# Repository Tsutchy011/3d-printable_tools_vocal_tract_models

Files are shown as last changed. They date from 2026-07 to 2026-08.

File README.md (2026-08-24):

# 3D printable tools for vocal tract models

声道模型を用いた音響教育（音源フィルタ理論のデモンストレーション・実習）のために作成した、
3Dプリンタで印刷可能なモデル一式です。

上智大学 荒井研究室「音響音声学デモンストレーション (Acoustic-Phonetics Demonstrations; APD)」で公開されている
**日本語5母音の声道模型 (VTM-T20)** に対応するリード式音源・ケースの他、
スライド式3音響管・それに対応するリード式音源、リードを切り出すための治具などのアタッチメントを収録しています。

- 出典: 辻慎也, 荒井隆行, 「3Dプリンタを活用した音響教育のための教材作成
  ——言語聴覚士養成コースでの取り組み事例——」, 日本音響学会講演論文集, Sep. 2026.
  
- 関連:
  - [Acoustic-Phonetics Demonstrations (APD)](https://splab.net/apd/)
  - [日本語5母音の声道模型（VTM-T20）](https://splab.net/apd/v100/)
  - [本モデルが対応している教科書（最新言語聴覚講座 音響学）](https://store.isho.jp/search/detail/productId/2607204890)

> **License:** [CC BY 4.0](https://creativecommons.org/licenses/by/4.0/)  
> 辻慎也・荒井隆行（上智大学）, *3D printable tools for vocal tract models*, 2026.  
> https://github.com/Tsutchy011/3d-printable_tools_vocal_tract_models
>
> なお本アタッチメントの一部は、上智大学荒井研究室が公開する声道模型 VTM-T20 に
> 対応するよう設計したものです。VTM-T20 本体のデータは上記のリンクよりダウンロードできます。<br>
> その利用については APD の利用条件に従ってください。
> https://splab.net/apd/termsofuse

---

## 1. 動作環境

| 項目 | 本稿で使用したもの |
|---|---|
| 3D CAD | OpenSCAD 2021.01 |
| スライサー | eufyMake Studio 3D (Anker) |
| 3Dプリンタ | AnkerMake M5 (Anker), 造形範囲 235 × 235 × 250 mm |
| 素材 | PLA |

`.scad` を編集すれば寸法を変更できます。<br>
編集せずに使う場合は `.stl` をそのままスライサーに読み込んでください。

---

## 2. ファイル一覧

```
3d-printable_tools_vocal_tract_models/
├── 01_スライド式3音響管/
├── 02_リード式音源/
├── 03_リード裁断用の治具_リードケース/
├── 04_ケース類/
└── 05_空気ポンプ用の追加パーツ/
```

各パーツにつき `.stl`（そのまま印刷可）と `.scad`（寸法を変更したい場合の設計ファイル）を
同じフォルダに収めています。

### 2-1. スライド式3音響管

| ファイル | 内容 | ソース |
|---|---|---|
| `01_スライド式3音響管/acoustic_tube_ID20mm_170mm.stl` | スライド式3音響管の音響管本体です。 | `acoustic_tube_ID20mm_170mm.scad` |
| `01_スライド式3音響管/sliding_three_tube_part.stl` | 狭めのスライダーと、それを操作するトロンボーン式ロッドのセットです。 | `sliding_three_tube_part.scad` |

> 音響管本体は透明な素材でプリントしていただくか、透明アクリル管（市販のもの; 内径20 mm）を音響管の代わりに使うと、
> スライダーの動きが見えるため教育効果が高くなります。

### 2-2. リード式音源

| ファイル | 内容 | ソース |
|---|---|---|
| `02_リード式音源/reed_type_sound_source_ID20mm_S3T.stl` | **スライド式3音響管用** の音源部分本体です。 | `リード式音源部分_2パターンで出力.scad` (`"20MM"`) |
| `02_リード式音源/reed_type_sound_source_ID10mm_VTM.stl` | **VTM-T20用** の音源部分本体です。 | 同上 (`"10MM"`) |
| `02_リード式音源/reed_fixing_part_200μm.stl` | **リードの厚み0.2 mm 用** のリード固定パーツです。 | `リード部分.scad` (`reed_thickness = 0.2`) |
| `02_リード式音源/reed_fixing_part_300μm.stl` | **リードの厚み0.3 mm 用** のリード固定パーツです。 | 同上 (`reed_thickness = 0.3`) |

### 2-3. リード裁断用の治具・リードケース

| ファイル | 内容 | ソース |
|---|---|---|
| `03_リード裁断用の治具_リードケース/reed_cutter.stl` | リード裁断治具。4パーツを一括して印刷できるよう配置してあります。 | `reed_cutter.scad` (`"ALL"`) |
| `03_リード裁断用の治具_リードケース/reed_case.stl` | リードケース（本体カートリッジ＋保護スリーブ） | `reed_case.scad` |

### 2-4. ケース類

| ファイル | 内容 | ソース |
|---|---|---|
| `04_ケース類/VTM_T20_case.stl` | VTM-T20 収納・展示ケースの本体（5本用） | `VTM_T20_case.scad` |
| `04_ケース類/VTM_T20_case_lid.stl` | 同ケースの蓋。5本を固定するペグ付き | `VTM_T20_case_lid.scad` |

### 2-5. 空気ポンプ用の追加パーツ

| ファイル | 内容 | ソース |
|---|---|---|
| `05_空気ポンプ用の追加パーツ/reed_flow_reducer.stl` | リード式音源用の気流リデューサ | `reed_flow_reducer.scad` |

> 空気ポンプで2-2のリード式音源を駆動した場合、過剰に励起していい音になりにくいことがあります。<br>
> その場合には、上記の気流リデューサを空気ポンプとリード式音源の間に接続してお使いください。

---

## 3. 印刷のコツ（パーツ別）

各STLはサポート材不要の姿勢で保存しています。

### 音響管 `acoustic_tube_ID20mm_170mm.stl`
- **立てて（縦置きで）**印刷する配置になっています。
- 高さ 170 mmで接地面が細いため**ブリム（brim）を推奨**します。
- 内径は 20.0 mm ではなく **20.3 mm** で設計しています。樹脂の収縮を見込んだ値で、
  出力後の実寸がおよそ 20 mm になります。**内径が小さすぎる場合はこの補正値
  (`hole_compensation`) を大きく**してください。
- 外周の3点リブは反り・たわみ防止用です。

### スライダーとロッド `sliding_three_tube_part.stl`
- スライダーは**立てて**、ロッドは**寝かせて**印刷する配置になっています。
  （この向きならサポート材は不要で、ロッドも折れにくくなります）
- ロッドの穴に差し込むと固定されるように作られていますが、固定されない場合には接着剤などお使いください。
- 管内での動きが悪い場合は `body_outer_dia`（既定 19.6 mm）を 0.1 mm 単位で小さくします。

### リード式音源カプセル
- **プラグを上にして逆さに置いた状態**にしてあります。
- プラグが固くて入らない／緩い場合は、`.scad` の `plug_outer_diameter`
  （VTM-T20用 9.7 mm）や `plug_tip_diameter` / `plug_root_diameter`
  （3音響管用 19.5 / 19.9 mm）を 0.1 mm 単位で調整してください。

### リード固定パーツ
- スリット高は `reed_thickness + slot_vertical_clearance`（既定 0.05 mm）です。
  **シートが入らない場合は `slot_vertical_clearance` を 0.05 → 0.1 に増やして**ください。
- 逆にリードがすぐ抜ける場合はこの値を 0 に近づけます。

### リード裁断治具 `reed_cutter.stl`
- 長辺 **195 mm** です。造形範囲がこれより小さいプリンタでは、
  `.scad` の `render_target` を `"STRIP_BASE"` / `"STRIP_TOP"` / `"CHOP_BASE"` / `"CHOP_TOP"`
  に切り替えて**個別に印刷**してください。

### ケース類
- ケース本体・蓋はいずれも**天面を下にした状態**で、印刷時のサポート材は不要です。
- 蓋がきつい／緩い場合は `.scad` の `clearance_top`（既定 0.6 mm）と
  `clearance_bottom`（既定 −0.1 mm）で調整します。
  **`clearance_bottom` を負の値にしているのが摩擦固定のポイント**です。
- 横幅がAnkerMakeの印刷サイズギリギリなため、スライサーの設定でZ軸を45˚回転させてください。

---

## 4. 印刷設定の目安

eufyMake Studio 3Dでは、デフォルトの設定で問題なく印刷できました。
以下ではその値を共有します:

| 項目 | 目安 | eufyMakeのデフォルト値 | 備考 |
|---|---|---|---|
| 積層ピッチ | 0.15〜0.20 mm | 0.20 mm | 特になし |
| 壁（外周）数 | 3〜4 | 3 | 音響管・カプセルは気密性のため多めに |
| インフィル | 20〜30% | 15% | ケース類は 15% 程度でも可 |
| サポート材 | **基本的に不要です** | サポートなし | 各STLはサポート不要の姿勢で保存しています |
| ブリム | 音響管・長尺パーツで推奨 | ブリムタイプ: オート | 接地面積が小さいものでオンにすると良いです |
| ノズル温度 / ベッド温度 | PLA 標準 | 230˚ | ノズル温度は215˚くらいがおすすめです |

---

## 5. 組み立てと使い方

1. **リードを切り出す** — 大きい方の裁断治具にクリアファイル等のシートを挟み、カッターで幅 10 mmの短冊状に切り出します。
   その後、小さい方の器具により長さ 30 mmになるよう切っていきます。
   切ったリードはリードケースに保管できます。
2. **リード固定パーツにリードを差し込む** — 1. のシート厚に対応するパーツ
   （0.2 mm 用 / 0.3 mm 用）のスリットにリードを差し込みます。
3. **音源カプセルに挿入する** — 固定パーツを音源本体のリード室に押し込みます。
4. **声道模型に接続する** — VTM-T20 なら 10 mm 用、スライド式3音響管なら 20 mm 用の
   本体を使います。
5. **気流を送る** — 呼気、または空気ポンプでカプセル後端から気流を送ると母音が生成されます。

> 音が鳴らないときは、①気流の勢い、②リードの差し込み量と固定具合、
> を確認してください。

---

## 6. 引用

本アタッチメントを利用された場合は、以下をご参照ください。

```
辻慎也, 荒井隆行, "3Dプリンタを活用した音響教育のための教材作成
——言語聴覚士養成コースでの取り組み事例——", 日本音響学会講演論文集, Sep. 2026.
```

## 7. 謝辞

本モデルの作成に際して、生成AIを補助的に利用しました。
一部の教材は、上智大学四谷キャンパスおよび Sixth Joint Meeting Acoustical Society of
America and Acoustical Society of Japan にて開催された、音声生成の音響理論に関する
ワークショップで用いられた教材から発想を得ました。
3Dプリンタの運用・リード式音源の印刷などに関して、鈴木良平氏、渡邊梨子氏に
ご助言をいただきました。

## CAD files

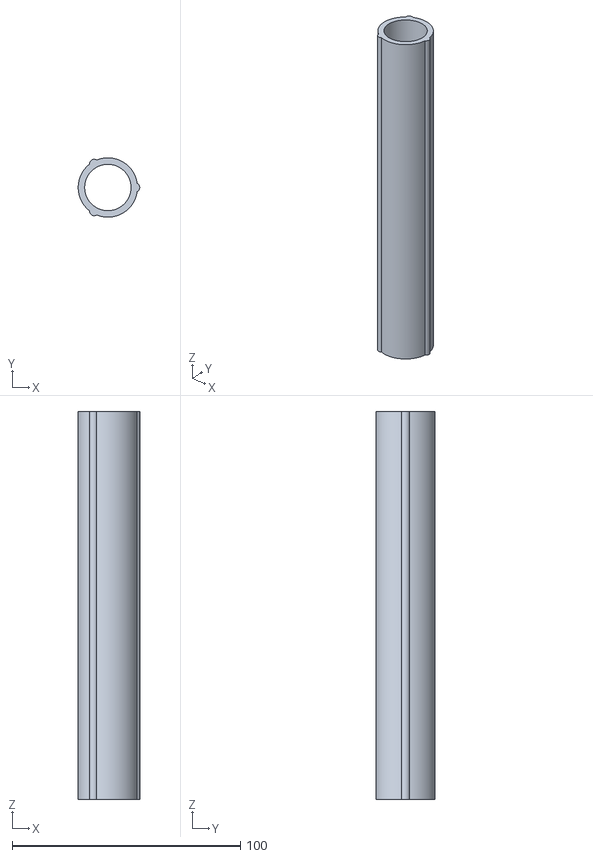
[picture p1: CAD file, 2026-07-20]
01_スライド式3音響管/acoustic_tube_ID20mm_170mm.stl
27.0 x 26.0 x 170.0

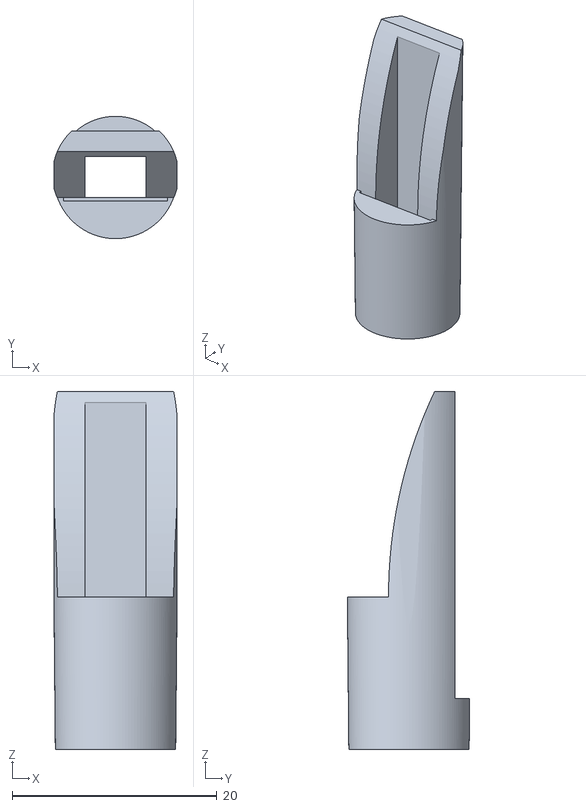
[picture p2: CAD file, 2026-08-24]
02_リード式音源/reed_fixing_part_300μm.stl
12.0 x 12.0 x 35.0

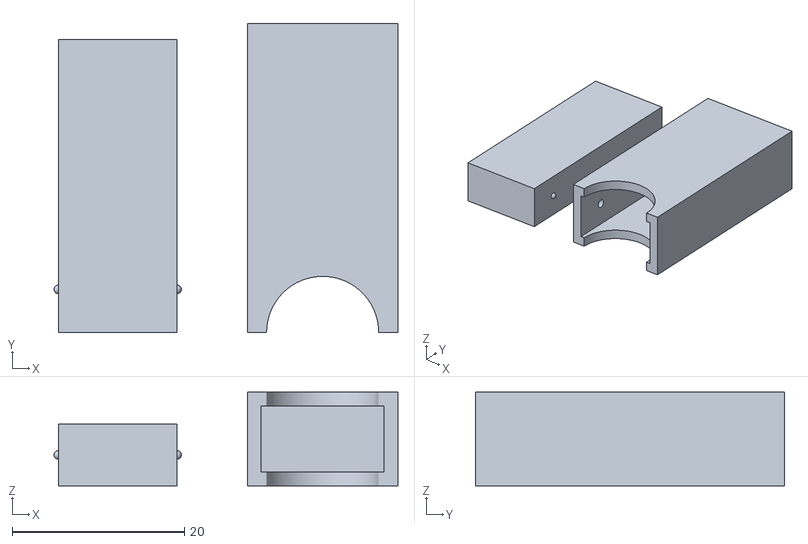
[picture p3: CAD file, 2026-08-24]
03_リード裁断用の治具_リードケース/reed_case.stl
39.9 x 35.8 x 10.9

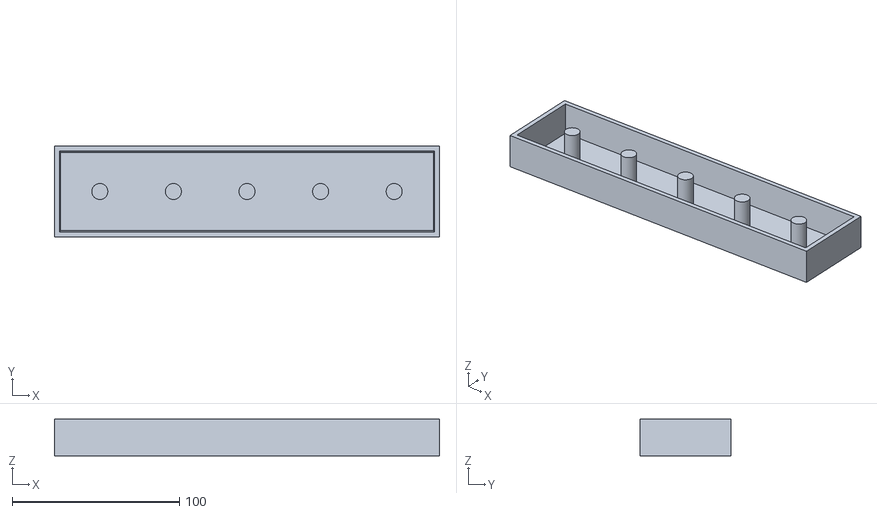
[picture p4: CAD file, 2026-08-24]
04_ケース類/VTM_T20_case_lid.stl
230.2 x 54.2 x 22.0

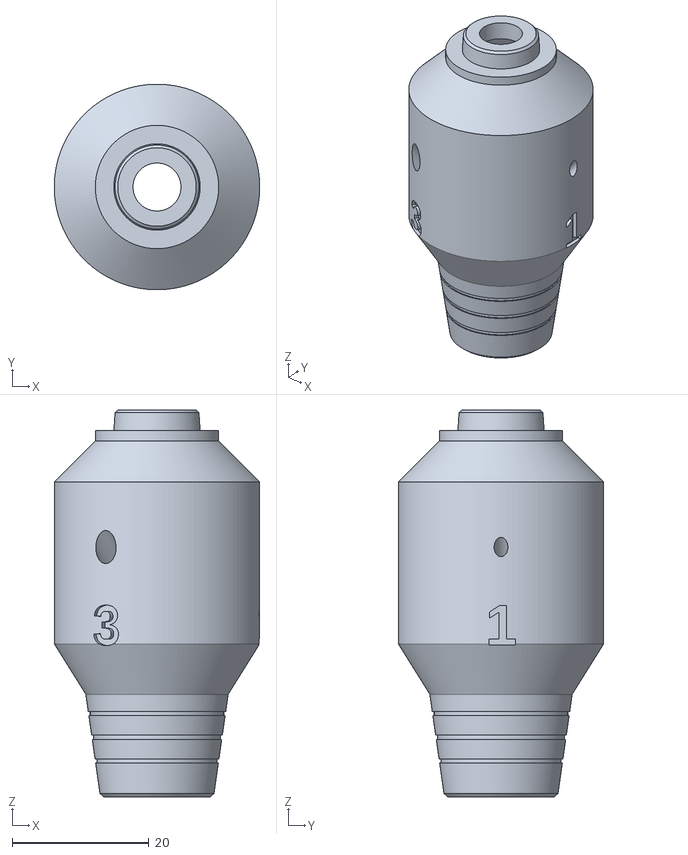
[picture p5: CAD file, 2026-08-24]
05_空気ポンプ用の追加パーツ/reed_flow_reducer.stl
30.0 x 30.0 x 56.5

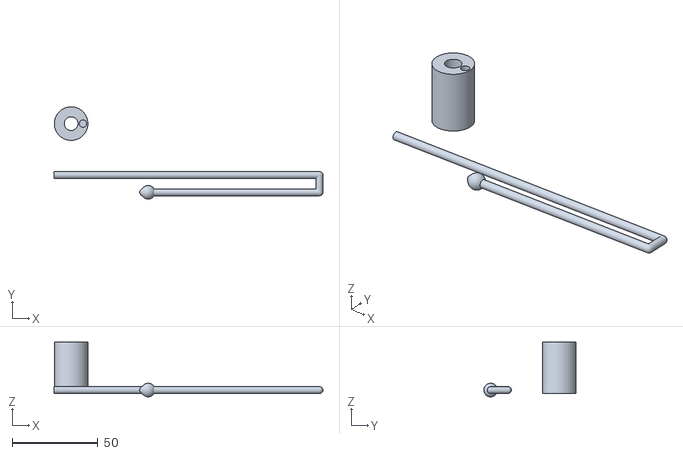
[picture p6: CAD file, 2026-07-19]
01_スライド式3音響管/sliding_three_tube_part.stl
157.0 x 53.9 x 32.0

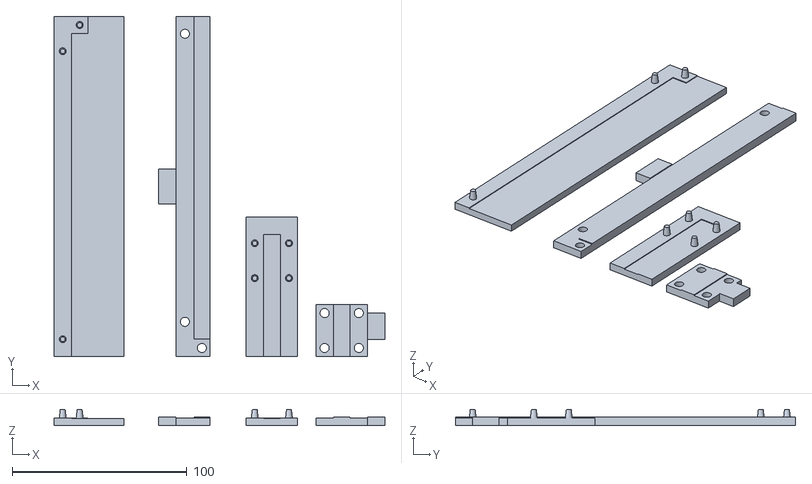
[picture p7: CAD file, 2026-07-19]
03_リード裁断用の治具_リードケース/reed_cutter.stl
189.6 x 195.0 x 9.40

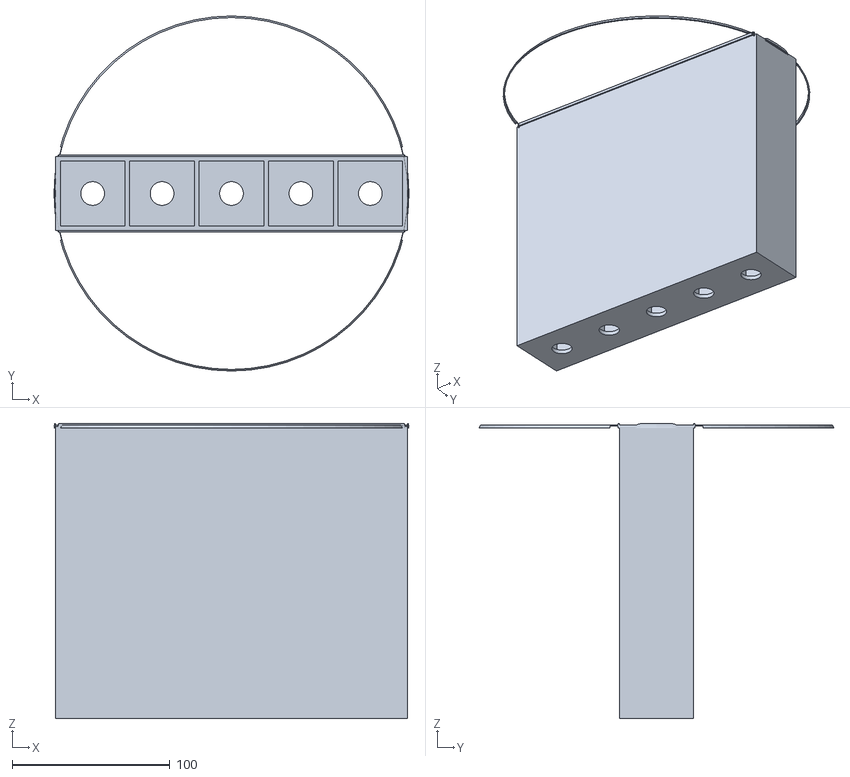
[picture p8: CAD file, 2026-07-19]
04_ケース類/VTM_T20_case.stl
225.0 x 225.0 x 187.0

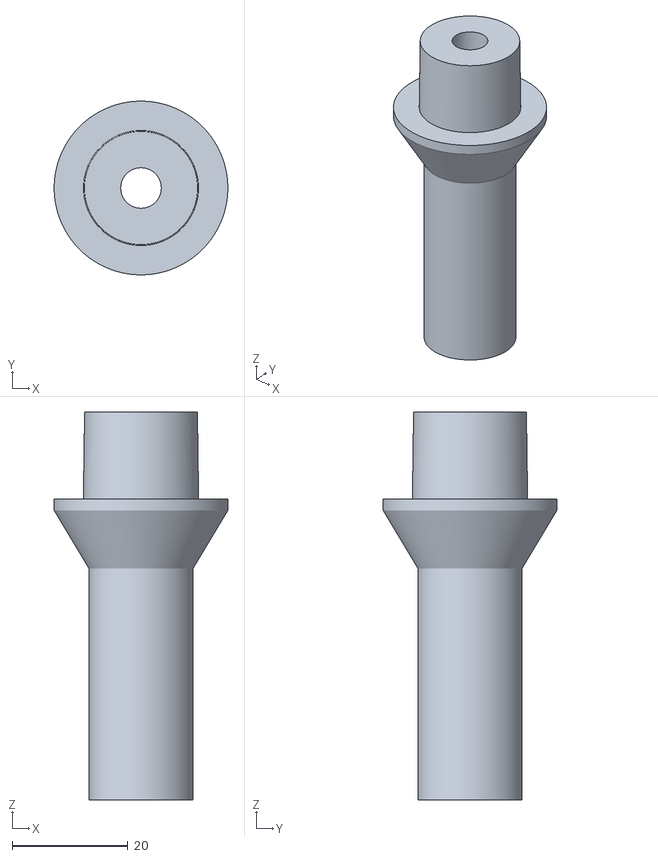
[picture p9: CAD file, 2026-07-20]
02_リード式音源/reed_type_sound_source_ID20mm_S3T.stl
30.0 x 30.0 x 67.0

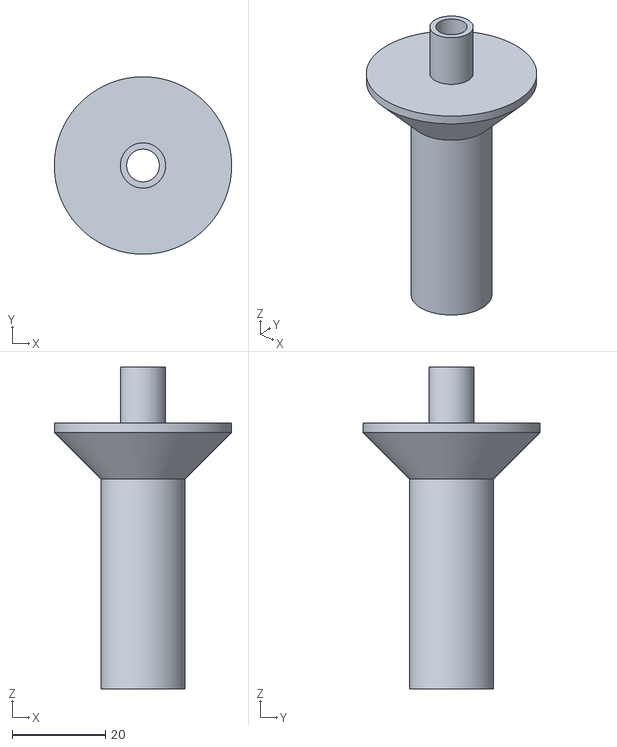
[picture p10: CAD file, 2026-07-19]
02_リード式音源/reed_type_sound_source_ID10mm_VTM.stl
38.0 x 38.0 x 69.0

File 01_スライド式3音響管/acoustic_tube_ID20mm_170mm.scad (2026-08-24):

// --- 3Dプリント用 17cm音響管 ---

// [管の基本寸法]
tube_length = 170.0;     
tube_outer_dia = 26.0;   

// [内径と3Dプリント用補正]
base_inner_dia = 20.0;   
hole_compensation = 0.3; 
actual_inner_dia = base_inner_dia + hole_compensation;

rib_count = 3;         // 最低限の揺れ防止を担保する3本（三脚の原理）
rib_dia = 4.0;         // リブの太さ（丸み）
rib_protrusion = 1.0;  // 表面からの出っ張り量

$fn = 200; 

module subtle_rib_tube() {
    difference() {
        union() {
            // 1. 外側の円柱
            cylinder(h = tube_length, d = tube_outer_dia);
            
            // 丸リブ（3本）
            for (i = [0 : rib_count - 1]) {
                rotate([0, 0, i * (360 / rib_count)])
                    // 管の中心側にリブを押し込み、1mmだけ頭を出す計算式
                    translate([(tube_outer_dia / 2) - (rib_dia / 2) + rib_protrusion, 0, 0])
                        cylinder(h = tube_length, d = rib_dia, $fn = 60);
            }
        }
        
        // 2. 内側のくり抜き（貫通して真っ直ぐな管）
        translate([0, 0, -1])
            cylinder(h = tube_length + 2, d = actual_inner_dia);
    }
}

// 煙突のように立ててプリント
subtle_rib_tube();

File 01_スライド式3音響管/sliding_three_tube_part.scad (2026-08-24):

// --- 3Dプリント用 スライド式3音響管のパーツ ---

// [寸法設定]
body_length = 30.0;
body_outer_dia = 19.6;      // 20mm管用のスライダー外径
hole_dia = 8.0;             // 狭めの内径は8mm
rod_offset = 6.9;           // 8mm穴と外壁の「真ん中」にロッドが来るように
rod_dia = 4.0;              // 棒の太さ
inner_rod_length = 145.0;   // 内側の棒の長さ
outer_rod_length = 100.0;   // 外側の棒（持ち手）の長さ
tube_outer_dia = 26.0;      // 音響管の外径
outer_offset = (tube_outer_dia / 2) + (rod_dia / 2) + 2.0; 

$fn = 60; // 滑らかさ

// --- 1. スライダー本体（立ててプリント） ---
translate([0, 20, 0]) {
    difference() {
        cylinder(h = body_length, d = body_outer_dia, center = false);
        
        // 狭めの内径: 8mm
        translate([0, 0, -1]) cylinder(h = body_length + 2, d = hole_dia, center = false);
        
        // ロッドを差し込むための穴（深さ10mm）
        translate([rod_offset, 0, body_length - 10]) 
            cylinder(h = 11, d = rod_dia + 0.3, center = false);
    }
}

// --- 2. トロンボーンロッド（寝かせてプリント） ---
translate([0, -10, rod_dia/2]) {
    union() {
        // 本体に差し込むための10mmを余分に長くしています
        translate([-10, 0, 0])
            rotate([0, 90, 0]) cylinder(h = inner_rod_length + 10, d = rod_dia);
        
        // 折り返し（Uターン）部分
        hull() {
            translate([inner_rod_length, 0, 0]) sphere(d = rod_dia);
            translate([inner_rod_length, -(outer_offset - rod_offset), 0]) sphere(d = rod_dia);
        }
        
        // 外側のロッド（持ち手）
        translate([inner_rod_length - outer_rod_length, -(outer_offset - rod_offset), 0])
            rotate([0, 90, 0]) cylinder(h = outer_rod_length, d = rod_dia);
            
        // グリップ（指掛け）
        translate([inner_rod_length - outer_rod_length, -(outer_offset - rod_offset), 0])
            hull() {
                sphere(d = rod_dia + 4);
                translate([-3, 0, 0]) sphere(d = rod_dia);
            }
    }
}

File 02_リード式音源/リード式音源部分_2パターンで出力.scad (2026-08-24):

// --- 3Dプリント用 リード式音源 本体部分 ---

// ★出力するパーツを選んでください★
// "10MM" : 10mm声道模型用（ストレートプラグ）
// "20MM" : 20mmアクリル音響管用（テーパー付きプラグ）
// "ALL"  : 両方並べて表示（一気に印刷用）
render_target = "ALL"; 

// [表示設定] 
show_cross_section = false;   // 断面を見たい時は true に変更

// [リード式音源の共通設定]
reed_chamber_length = 40.0;
reed_insert_dia_top = 12.8;
reed_insert_dia_bottom = 12.0;
capsule_outer_diameter = 18.0;
taper_height = 10.0;

$fn = 240; // 滑らかさ（出力用高精度）

// ==========================================
// モジュール1: 10mm声道模型用
// ==========================================
module reed_capsule_10mm() {
    plug_outer_diameter = 9.7;
    plug_inner_diameter = 7.0; 
    plug_length = 12.0;
    flange_diameter = 38.0;
    flange_thickness = 2.0;

    difference() {
        union() {
            cylinder(h = plug_length, d = plug_outer_diameter, center = false);
            translate([0, 0, plug_length]) cylinder(h = flange_thickness, d = flange_diameter, center = false);
            translate([0, 0, plug_length + flange_thickness]) cylinder(h = taper_height, d1 = flange_diameter, d2 = capsule_outer_diameter, center = false);
            translate([0, 0, plug_length + flange_thickness + taper_height]) cylinder(h = reed_chamber_length, d = capsule_outer_diameter, center = false);
        }
        // 音の直結ルート（貫通穴）
        translate([0, 0, -1]) cylinder(h = plug_length + flange_thickness + taper_height + 1, d = plug_inner_diameter, center = false);
        // リード室
        translate([0, 0, plug_length + flange_thickness + taper_height])
            cylinder(h = reed_chamber_length + 1, d1 = reed_insert_dia_bottom, d2 = reed_insert_dia_top, center = false);
    }
}

// ==========================================
// モジュール2: 20mmアクリル管用（テーパー付きオス型）
// ==========================================
module reed_capsule_20mm() {
    plug_tip_diameter = 19.5;
    plug_root_diameter = 19.9;
    plug_inner_diameter = 7.0;
    plug_length = 15.0;
    flange_diameter = 30.0;
    flange_thickness = 2.0;

    difference() {
        union() {
            cylinder(h = plug_length, d1 = plug_tip_diameter, d2 = plug_root_diameter, center = false);
            translate([0, 0, plug_length]) cylinder(h = flange_thickness, d = flange_diameter, center = false);
            translate([0, 0, plug_length + flange_thickness]) cylinder(h = taper_height, d1 = flange_diameter, d2 = capsule_outer_diameter, center = false);
            translate([0, 0, plug_length + flange_thickness + taper_height]) cylinder(h = reed_chamber_length, d = capsule_outer_diameter, center = false);
        }

        translate([0, 0, -1]) cylinder(h = plug_length + flange_thickness + taper_height + 1, d = plug_inner_diameter, center = false);
        
        // リード室
        translate([0, 0, plug_length + flange_thickness + taper_height])
            cylinder(h = reed_chamber_length + 1, d1 = reed_insert_dia_bottom, d2 = reed_insert_dia_top, center = false);
    }
}

// ==========================================
// 描画・配置の統合管理モジュール
// ==========================================
module render_all_parts() {
    // それぞれの高さを計算（ひっくり返してZ=0に揃えるため）
    z_offset_10mm = 12.0 + 2.0 + 10.0 + 40.0; // plug + flange + taper + chamber
    z_offset_20mm = 15.0 + 2.0 + 10.0 + 40.0; 

    if (render_target == "10MM") {
        translate([0, 0, z_offset_10mm]) rotate([180, 0, 0]) reed_capsule_10mm();
    } else if (render_target == "20MM") {
        translate([0, 0, z_offset_20mm]) rotate([180, 0, 0]) reed_capsule_20mm();
    } else if (render_target == "ALL") {
        // ぶつからないように左右にズラして配置
        translate([-25, 0, z_offset_10mm]) rotate([180, 0, 0]) reed_capsule_10mm();
        translate([ 25, 0, z_offset_20mm]) rotate([180, 0, 0]) reed_capsule_20mm();
    }
}

// --- 最終実行部（断面表示機能） ---
if (show_cross_section) {
    difference() {
        render_all_parts();
        translate([-50, -100, -10]) cube([100, 100, 100]); // 手前半分をカット
    }
} else {
    render_all_parts(); // 通常の出力
}

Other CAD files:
02_リード式音源/reed_fixing_part_200μm.stl
02_リード式音源/リード部分.scad
03_リード裁断用の治具_リードケース/reed_case.scad
03_リード裁断用の治具_リードケース/reed_cutter.scad
04_ケース類/VTM_T20_case.scad
04_ケース類/VTM_T20_case_lid.scad
05_空気ポンプ用の追加パーツ/reed_flow_reducer.scad

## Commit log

2026-07-20 Revert "Delete 3音響管部分_v3.stl"
    This reverts commit fb9bda58b145c4b75677a4e0c5d797e4cc3946ae.
    [3音響管部分_v3.stl]
2026-07-20 Revert "Add files via upload"
    This reverts commit d70300c78d2161cbaa05cf69663de60f5884ba7b.
    [3音響管部分.stl, VTM_case.stl, リードケース.stl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]
2026-08-24 modified_files
    公開用に、諸々整備しました。
    [VTM_T20_case.scad, VTM_T20_case.stl, VTM_T20_case_lid.scad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]
2026-08-24 Update README: 関連リンク・ファイル一覧・印刷のコツを整理
2026-10-29 Add reed fixing part for 0.1 mm reeds and LICENSE (v1.1.0)
    - 02_リード式音源/reed_fixing_part_100μm.stl: リード厚0.1 mm用（スリット0.15 mm）を追加
    - 02_リード式音源/リード部分.scad: reed_thickness の選択肢の説明に 0.1 を追加
    - LICENSE: CC BY 4.0 の全文を追加
    - README: ファイル一覧・印刷のコツ・使い方に0.1 mm用を追記し、LICENSE への参照と更新履歴を追加
